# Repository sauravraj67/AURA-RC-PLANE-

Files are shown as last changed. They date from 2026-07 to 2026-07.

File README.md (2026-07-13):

# AURA-RC-PLANE-



I made a custom Tailless twin motor RC Plane with custom Flight Controller (based on STM32). The Flight Controller  will have a  IMU's and a barometer for precise data collection. The Plane design will include a tailless structure and the motions will be controlled by the flaps on the wings.

## Features
- Base on  STM32F401CBUx 
- Has dual IMU (MPU_6050)
- Has a Barometer (BMP280)
- Uses 2 Light-Weight Servoes
- Uses Custom flight-controller
- Tailless twin motor Design

### Schematic



###  PCB Design




### 3D Design


618795488-89bd397e-2dfa-4107-a2a6-26ff834b6018
618795522-03c98845-beb9-4136-b775-faca25e47061

## 📦 Bill of Materials

| Item | Quantity | Unit Price (USD) | Total Price (USD) | Source |
|---|:---:|---:|---:|---|
| PCB + PCBA | 1 | $154.46 | $140.56 | https://jlcpcb.com |
| PCB Shipping | 1 | $17.32 | $23.24 | https://jlcpcb.com |
| Brushless Motor | 2 | $15.20 | $30.40 | https://robu.in/product/r2207-2207-2450kv-ccw-fpv-brushless-motor/ |
| ESC | 2 | $8.91 | $17.82 | https://robocraze.com/products/simplifly-esc-30a-2s-6s-for-bldc-motors-with-d-shot-oneshot125 |
| Receiver / Transmitter | 1 | $62.00 | $62.00 |https://robocraze.com/products/fly-sky-fs-i6x-2-4ghz-6ch-afhds-2a-rc-transmitter-with-fs-ia10b-2-4ghz-10ch-receiver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 |
| 12V Battery | 1 | $5.78 | $5.78 | https://robocraze.com/products/11-1v-2200mah-li-ion-battery?_pos=18&_sid=25292ddd5&_ss=r |
| SG90 Servo | 2 | $0.96 | $1.92 | https://robocraze.com/products/sg90-micro-servo-motor?_pos=1&_sid=88e48e080&_ss=r |
| 3D Printed Plane | 1 | $0 | $0 | #Printing-legion |

## 💰 Cost Summary

| Category | Amount (USD) |
|---|---:|
| Total Component Cost | **$283.58** |

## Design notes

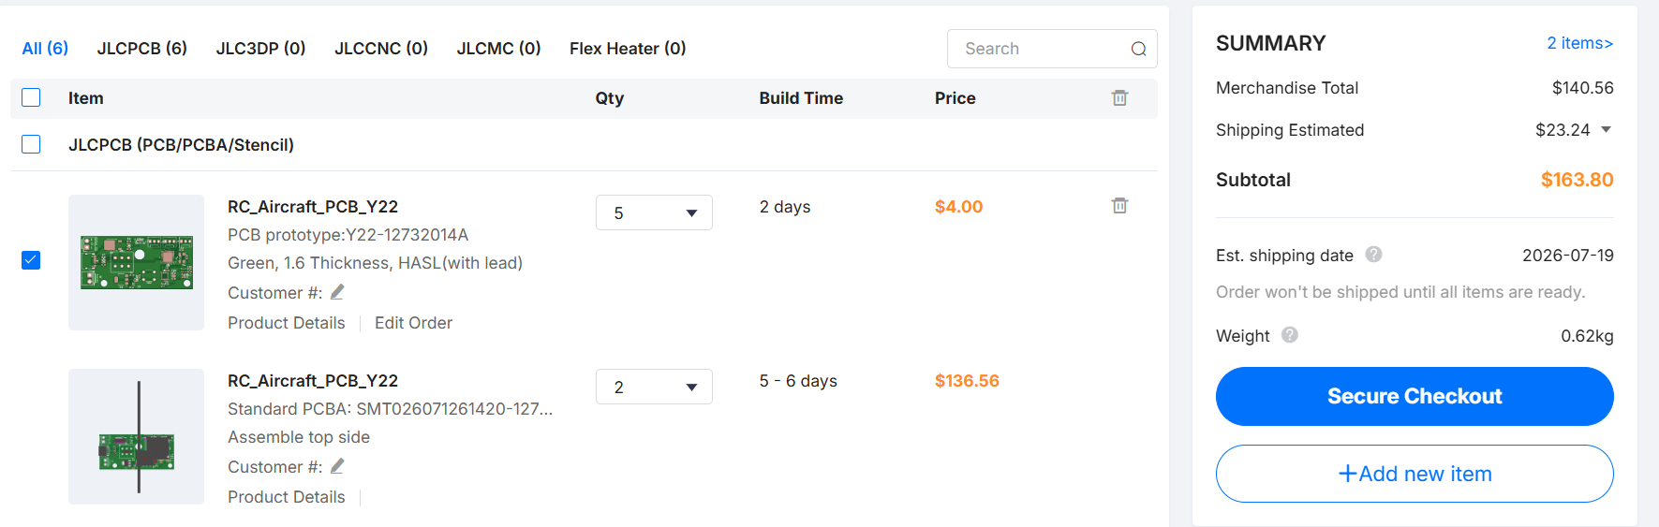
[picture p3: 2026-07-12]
Payment-ScreenShot/Screenshot 2026-07-13 011824.png

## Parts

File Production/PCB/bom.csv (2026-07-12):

Designator | Footprint | Quantity | Value | LCSC Part #
C1, C3, C7 | 0603 | 3 | 10 uf
C10, C9 | 0603 | 2 | 100nf
C11, C12 | 0603 | 2 | 12 pf
C13, C15, C16, C17 | 0603 | 4 | 100 pf
C2, C4, C5, C8 | 0603 | 4 | 0.1uf
C6 | 0603 | 1 | 2.2 uf
D1, D2 | 0201 | 2 | LED
J1 | USB_C_Receptacle_HRO_TYPE-C-31-M-12 | 1 | USB_C_Receptacle_USB2.0_16P
J2, J6 | JWT_A3963_1x02_P3.96mm_Vertical | 2 | Conn_01x02_Pin
J3, J4, J5 | FanPinHeader_1x03_P2.54mm_Vertical | 3 | Conn_01x03_Pin
J7 | PinHeader_1x04_P1.00mm_Vertical | 1 | Conn_01x04_Pin
R1, R2 | 0603 | 2 | 33 R
R3 | 0603 | 1 | 50 K
R4 | 0603 | 1 | 50K
R5, R6 | 0603 | 2 | 1k
R7 | 0603 | 1 | 1 K
SW1 | SW_PUSH_E-Switch_FS5700DP_DPDT | 1 | SW_DPDT_x2
SW2 | SW_PUSH_6mm | 1 | SW_Push
U1 | SOT-223-3_TabPin2 | 1 | AMS1117-3.3
U2 | TO-252-2 | 1 | L7805
U3 | InvenSense_QFN-24_4x4mm_P0.5mm | 1 | MPU-6050
U4 | Bosch_LGA-8_2x2.5mm_P0.65mm_ClockwisePinNumbering | 1 | BMP280
U5 | QFN-48-1EP_7x7mm_P0.5mm_EP5.6x5.6mm | 1 | STM32F401CBUx
Y1 | Crystal_SMD_0603-4Pin_6.0x3.5mm | 1 | Crystal_GND24_Small

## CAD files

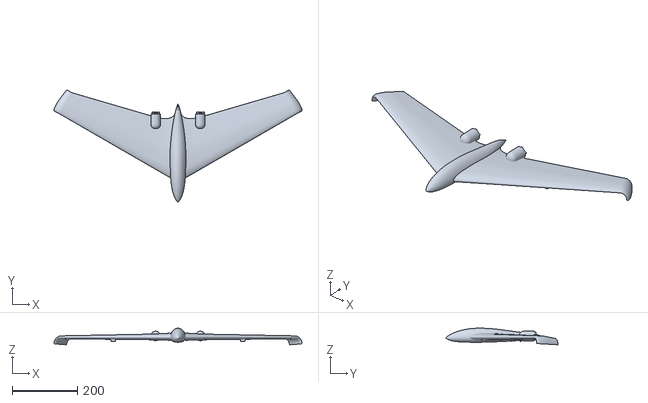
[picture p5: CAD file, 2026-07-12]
Production/CAD/AURA3D.stl
760.6 x 343.3 x 51.2

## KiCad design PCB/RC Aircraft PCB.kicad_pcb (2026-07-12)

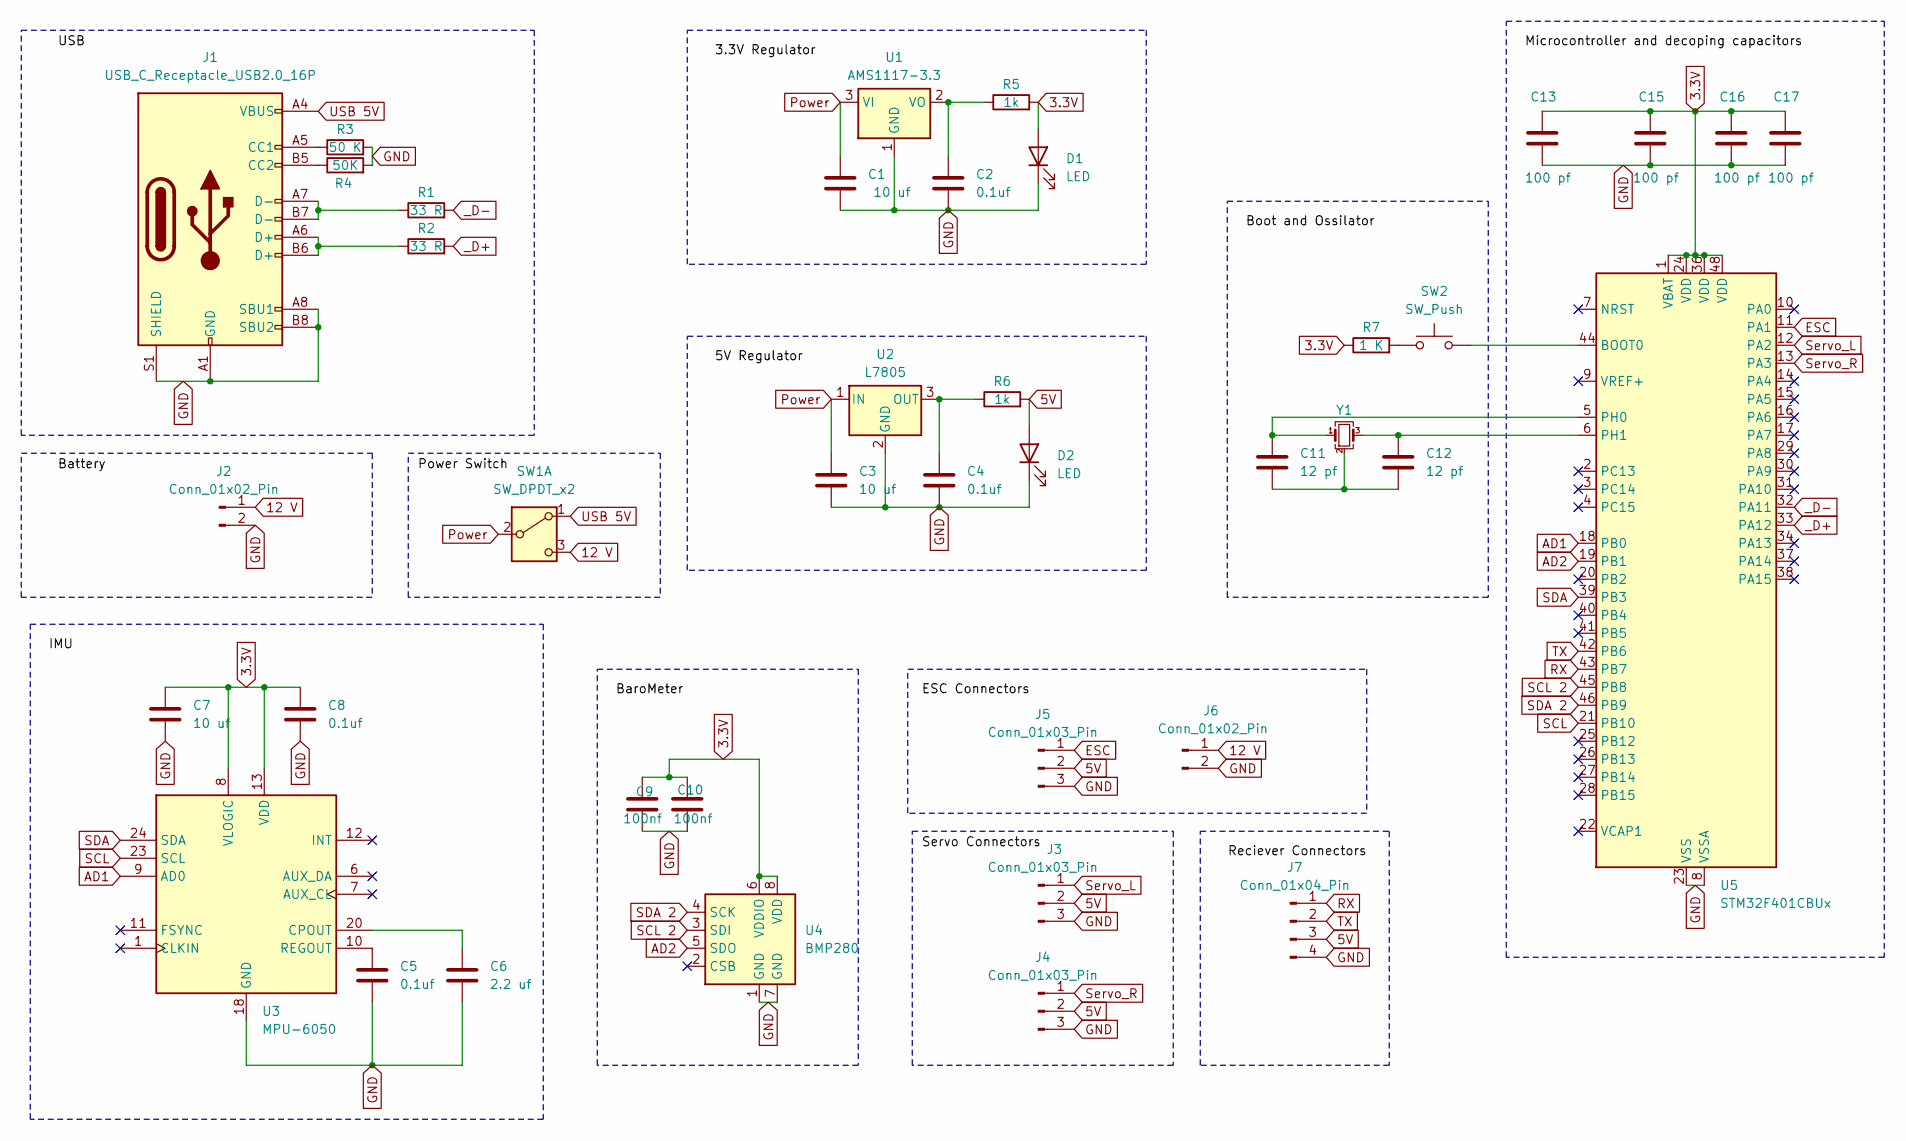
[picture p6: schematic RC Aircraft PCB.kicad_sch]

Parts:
C1, C3, C7: 10 uf; C_0603_1608Metric_Pad1.08x0.95mm_HandSolder
C2, C4, C5, C8: 0.1uf; C_0603_1608Metric_Pad1.08x0.95mm_HandSolder
C6: 2.2 uf; C_0603_1608Metric_Pad1.08x0.95mm_HandSolder
C9, C10: 100nf; C_0603_1608Metric_Pad1.08x0.95mm_HandSolder
C11, C12: 12 pf; C_0603_1608Metric_Pad1.08x0.95mm_HandSolder
C13, C15, C16, C17: 100 pf; C_0603_1608Metric_Pad1.08x0.95mm_HandSolder
D1, D2: LED; LED_0201_0603Metric
J1: USB_C_Receptacle_USB2.0_16P; USB_C_Receptacle_HRO_TYPE-C-31-M-12
J2, J6: Conn_01x02_Pin; JWT_A3963_1x02_P3.96mm_Vertical
J3, J4, J5: Conn_01x03_Pin; FanPinHeader_1x03_P2.54mm_Vertical
J7: Conn_01x04_Pin; PinHeader_1x04_P1.00mm_Vertical
R1, R2: 33 R; R_0603_1608Metric
R3: 50 K; R_0603_1608Metric
R4: 50K; R_0603_1608Metric
R5, R6: 1k; R_0603_1608Metric
R7: 1 K; R_0603_1608Metric
SW1: SW_DPDT_x2; SW_PUSH_E-Switch_FS5700DP_DPDT
SW2: SW_Push; SW_PUSH_6mm
U1: AMS1117-3.3; SOT-223-3_TabPin2
U2: L7805; TO-252-2
U3: MPU-6050; InvenSense_QFN-24_4x4mm_P0.5mm
U4: BMP280; Bosch_LGA-8_2x2.5mm_P0.65mm_ClockwisePinNumbering
U5: STM32F401CBUx; QFN-48-1EP_7x7mm_P0.5mm_EP5.6x5.6mm
Y1: Crystal_GND24_Small; Crystal_SMD_0603-4Pin_6.0x3.5mm

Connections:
3.3V: C7.1, C8.1, C9.1, C10.1, C13.1, C15.1, C16.1, C17.1, D1.2 (A), R5.2, R7.1, U3.8 (VLOGIC), U3.13 (VDD), U4.6 (VDDIO), U4.8 (VDD), U5.1 (VBAT), U5.24 (VDD), U5.36 (VDD), U5.48 (VDD)
5V: D2.2 (A), J3.2, J4.2, J5.2, J7.3, R6.2
12 V: J2.1, J6.1, SW1.3 (C)
AD1: U3.9 (AD0), U5.18 (PB0)
AD2: U4.5 (SDO), U5.19 (PB1)
ESC: J5.1, U5.11 (PA1)
GND: C1.2, C2.2, C3.2, C4.2, C5.2, C6.2, C7.2, C8.2, C9.2, C10.2, C13.2, C15.2, C16.2, C17.2, D1.1 (K), D2.1 (K), J1.A1 (GND), J1.A8 (SBU1), J1.A12 (GND), J1.B1 (GND), J1.B8 (SBU2), J1.B12 (GND), J1.S1 (SHIELD), J2.2, J3.3, J4.3, J5.3, J6.2, J7.4, R3.2, R4.2, U1.1 (GND), U2.2 (GND), U3.18 (GND), U4.1 (GND), U4.7 (GND), U5.8 (VSSA), U5.23 (VSS), U5.35 (VSS), U5.47 (VSS), U5.49 (VSS)
unnamed: C11.2, C12.2, Y1.2 (G), Y1.4 (G)
unnamed: J1.A5 (CC1), R3.1
unnamed: J1.B5 (CC2), R4.1
unnamed: J1.A6 (D+), J1.B6 (D+), R2.1
unnamed: J1.A7 (D-), J1.B7 (D-), R1.1
unnamed: R7.2, SW2.1
unnamed: C2.1, R5.1, U1.2 (VO)
unnamed: C4.1, R6.1, U2.3 (OUT)
unnamed: C6.1, U3.20 (CPOUT)
unnamed: C5.1, U3.10 (REGOUT)
unnamed: SW2.2, U5.44 (BOOT0)
unnamed: C11.1, U5.5 (PH0), Y1.1
unnamed: C12.1, U5.6 (PH1), Y1.3
Power: C1.1, C3.1, SW1.2 (B), U1.3 (VI), U2.1 (IN)
RX: J7.1, U5.43 (PB7)
SCL: U3.23 (SCL), U5.21 (PB10)
SCL 2: U4.3 (SDI), U5.45 (PB8)
SDA: U3.24 (SDA), U5.39 (PB3)
SDA 2: U4.4 (SCK), U5.46 (PB9)
Servo_L: J3.1, U5.12 (PA2)
Servo_R: J4.1, U5.13 (PA3)
TX: J7.2, U5.42 (PB6)
USB 5V: J1.A4 (VBUS), J1.A9 (VBUS), J1.B4 (VBUS), J1.B9 (VBUS), SW1.1 (A)
_D+: R2.2, U5.33 (PA12)
_D-: R1.2, U5.32 (PA11)

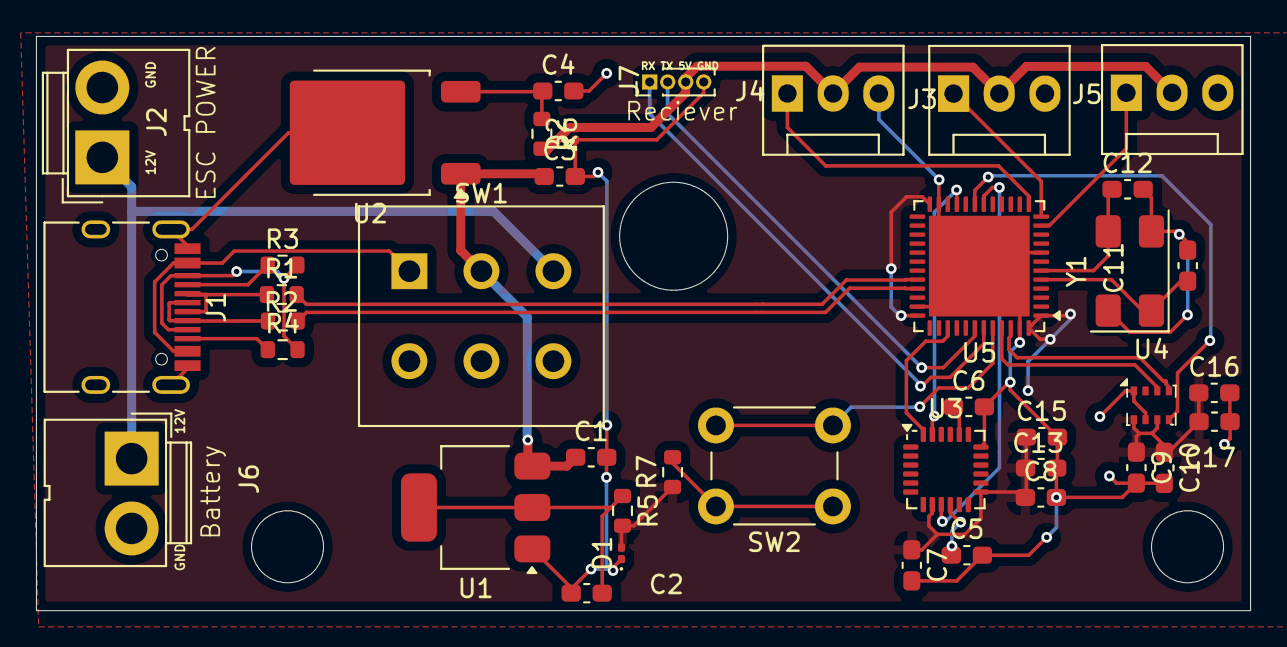
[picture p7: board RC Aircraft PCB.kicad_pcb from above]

Board: 2 copper layers, 67.4 x 31.9 mm, 40 parts (0 on the bottom side), 32 nets.

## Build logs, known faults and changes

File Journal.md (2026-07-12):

### So I am making an Custom RC Plane with custom Flight Controller

 ##  Schematics for Flight Controller
Hours - 6.1 hr

So I started with the schematics for my flight controller . I initially started with adding the USB-C ,12V battery connector and a 3 pin switch to switch between power from battery and USB-C as per the need them I made the circuit and added the labels then the STM32 and other sensores work on a constant 3.3V . So I added a 3.3V Voltage regulator (AMS1117-3.3) and made circuit for ir and added the required labels then the battery gives 12V but servos need 5V . So for that I added a 5V Voltage regulator (L7805) and made circuit for it and added the labels to them them as well after which  then I added the IMU (MPU5060) and barometer (BMP280) and made the required circuit for them and then I added the MCU (STM32F401CBUx) added the crystal oscillator circuit then I added the decoupling capacitors  added the boot button and attached all the labels from sensors , ESC ,Servos and USB to it as per it's pin outlet and this is the final look of the schematics  

## Making the PCB Layout 
hours :- 3.25 hr

So Now I started with the components placement . I First updated the PCB editor with all the components then I started arranging all the Component SET . I first made the USB-C circuit cluster arranged the required resistors around it then I started arranging the main chips in a very simple manner after that I started placing the Oscillator near to the MCU then I started arranging the IMU and barometer circuit . then I placed all the other components near to there connection and then I started forming a basic layout of the Board. IT is for a RC flight controller SO I would need to use a rectangular dimension instead of square for drones. then I placed the pins for batter ,servos and ESC made sure that they are near to there connection ,so that It is easy to rout . and after few alteration for ,I ended up with a final design. then I  added the boundary and added few holes on the PCB for connection ,Also I made sure that there is enough space for me to rout around the components. PCB (without rout)



## Routing the Fligh Controller 
hours :- 5.75 hr 

So I started with routing I initiated with the Data line connections , A connection hole was coming onto the path so for now I deleted it then I didn't specifically named the connection with _D+ and _D- without it kicad would do a differential pair , So I update the schematics then I made the differential pair for data lines. then I left the GND and 3.3V connections as I will use fil-zone on top layer for power and GND for bottom layer for stability. I used thicj traces for the 5V and 12V connections and I started making routs for the whole board one by one first I made the components circuit for sensors , routed the oscillator  to MCU then I started routing the 5v and 12v lines started routing the decoupling capacitors . I used vias where it was needed , made sure that the routs are clean and simple . I also had to made few changes on the PCB rout So that I can easily rout then I added 3.3V fillzone on top layer and GND fill zone to bottom layer and there were few miss connections , So I started solving them and then I used the Rules checker for any errors . I solved the major issues like  miss-Connections and rout near vias and holes  and left the basic the silkscreen ones. Then I added a text logo for the PCB and stared adding text for the naming the outpins and there connections . And this is the final looks of the Flight Controller PCB 

TOP Layer 



Bottom Layer 



3D View 



## Finalizing The Concept Design
hours :-  2.8 hr 

So Now I went and finalized the concept design . As I already Said before It will be a Tailless Twin motor RC Plane. So I kept that in mind and went and researched about that concept . After considering multiple design . I ended up liking one design then I selected a air-foil that would suit it and generated a reference design with TOP , FRONT and SIDE View of the plane with dimensions also with the Air-Foil. The Air-Foil I selected was MH-45 reflex . It is a 9.85%-thick reflex airfoil designed by Martin Hepperle specifically for flying wings and tailless model aircraft. So I added it as per my Design requirements. The Body Base is heavily inspired by
* Blended Wing-Body
* Sweepback Stability
* Integrated Twin Nacelles
And this is the final look of it



## Alligning the reference /Made the Fulelage 
hours :-  6.7 hr 

I loaded up the Fusion with the reference image then I Started aligning the reference to the exact size i wanted and then moved it to axis origin .I did it for all the 3 reference with as much precision as possible and this is how the 3D reference Canvas Lossets/6c143896-3292-4962-8e3e-9c78ffbe8cfb" />

. Then I made the side view Sketch of the main body


then I made the top view of the body


there were few sketch allignment issue so I solved them 


then after that I added offset plane for Rails . I  keeping in mind about the top/bottom sketch and the side sketches . In total I had to add about 19 of these offset planes and this is the look it looks


then for every offset plane I had to make rail . For that I needed to project Intersect all the for guildlines then use Spline to make that rails . this is how the first rail looked liked

and this was the end look after  I did it for all of the rails 


. It took me some times to reach here then I went to make the 3D model of the body using LOFT Feature but errors started showing up

I Tried to fix the errors but nothing much happened So I took a decision to rebuild it again because there wasn't any outcome I am goint to receive out of this . So Again I made the skectches of top and Side view





then again I went to make the model and waala this time things worked perfectly



Final Fuselage look 



## Made the Wings 
hours :-  3.4 hr 

So I made the airfoil first


then I aligned it to the fuselage

fter that I made the guild sketch's of the wing
hen I made the 3D model of the wing

then I extruded it and repeated the same for the other Side and this is how it looks 




then I added stabalizers to the end of the wings and this is the final look 



then I made cuts for mobility and component fixing 




## Finilized the CAD
hours :-  4.2 hr 

First I made the Surface to which I will attach the motors

then I added the rest of the eternal components like the Flight controller , Battery ,Receiver and ESC





that I added the servos to there respective position

Then I made respective cut's and fix for the servoes and the Brushless motors using sketch and offset plane tools 








So this is the final polished LOOK



## Made the firmware
hours :-  3.2  hr 

So I made a main firmware that Supercharges the Brain and then Wakes up the sensors and takes reading from them with calibration. the 200 Hz Flight Loop Reading and Fuse the data from the sensors from (IMU's and Barometer ) . Calculates acceleration ,gravity Wing speed . Then Use PID Stabilization . then reads the reading from the receiver and Controllers the Servos and ESC's accordingly as per the Input.



AND WITH THAT THE PROJECT COMES TO AN END !!!

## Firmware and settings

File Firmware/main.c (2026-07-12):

/*
 * ============================================================================
 * CUSTOM TAILLESS TWIN-MOTOR FLIGHT CONTROLLER FIRMWARE
 * Target MCU: STM32F401CBUx
 * ============================================================================
 */

#include "main.h"
#include <math.h>

// --- DEFINITIONS & CONSTANTS ---
#define MPU6050_ADDR    (0x68 << 1)
#define BMP280_ADDR     (0x76 << 1)
#define SBUS_FRAME_SIZE 25

// --- PERIPHERAL HANDLES ---
I2C_HandleTypeDef hi2c1;   // IMU 1 (MPU6050) via PB6/PB7
I2C_HandleTypeDef hi2c2;   // Barometer (BMP280) via PB10/PB3
TIM_HandleTypeDef htim1;   // ESCs (PA8, PA9)
TIM_HandleTypeDef htim2;   // Servos (PA0, PA1)
UART_HandleTypeDef huart1; // SBUS Receiver Input (PA10)

// --- FLIGHT CONTROL VARIABLES ---
float roll_input = 0.0f, pitch_input = 0.0f, throttle_input = 1000.0f;
float current_roll = 0.0f, current_pitch = 0.0f;
float gyro_bias_x = 0.0f, gyro_bias_y = 0.0f;

// PID Tuning Constants (Adjust these during test flights)
float Kp_roll = 1.2f,  Ki_roll = 0.05f,  Kd_roll = 0.1f;
float Kp_pitch = 1.5f, Ki_pitch = 0.05f, Kd_pitch = 0.1f;

// PID Memory Registers
float error_roll, integral_roll, derivative_roll, last_error_roll, out_roll;
float error_pitch, integral_pitch, derivative_pitch, last_error_pitch, out_pitch;

// SBUS Protocol Variables
uint8_t sbus_buffer[SBUS_FRAME_SIZE];
uint16_t sbus_channels[4];
uint8_t sbus_index = 0;
uint8_t is_armed = 0;
uint8_t rx_byte;

// Barometer Calibration Factors
uint16_t dig_T1; int16_t dig_T2, dig_T3; uint16_t dig_P1;
int16_t dig_P2, dig_P3, dig_P4, dig_P5, dig_P6, dig_P7, dig_P8, dig_P9;

// --- FUNCTION PROTOTYPES ---
void SystemClock_Config(void);
static void MX_GPIO_Init(void);
static void MX_I2C1_Init(void);
static void MX_I2C2_Init(void);
static void MX_TIM1_Init(void);
static void MX_TIM2_Init(void);
static void MX_USART1_UART_Init(void);

void IMU_Calibrate(void);
void IMU_Read(float *r, float *p);
void BMP280_Init(void);
float BMP280_GetAltitude(void);
void Mix_Elevons(float throttle, float roll, float pitch);

// --- MAIN PROGRAM EXECUTION ---
int main(void) {
    // Reset of all peripherals, Initializes the Flash interface and the Systick.
    HAL_Init();

    // Configure the system clock to 84 MHz using the 25MHz external crystal
    SystemClock_Config();

    // Initialize all configured peripherals
    MX_GPIO_Init();
    MX_I2C1_Init();
    MX_I2C2_Init();
    MX_TIM1_Init();
    MX_TIM2_Init();
    MX_USART1_UART_Init();

    // Device Sensors Boot & Calibration Sequence
    BMP280_Init();
    IMU_Calibrate();
    
    // Start Non-blocking UART Reception for RC Signal
    HAL_UART_Receive_IT(&huart1, &rx_byte, 1);

    // Start PWM Hardware Timers
    HAL_TIM_PWM_Start(&htim1, TIM_CHANNEL_1); // Left ESC
    HAL_TIM_PWM_Start(&htim1, TIM_CHANNEL_2); // Right ESC
    HAL_TIM_PWM_Start(&htim2, TIM_CHANNEL_1); // Left Servo
    HAL_TIM_PWM_Start(&htim2, TIM_CHANNEL_2); // Right Servo

    uint32_t loop_timer = HAL_GetTick();

    while (1) {
        // Main Flight Controller Loop (Executes strictly at 200Hz -> every 5ms)
        if ((HAL_GetTick() - loop_timer) >= 5) {
            loop_timer = HAL_GetTick();

            // 1. Refresh Flight Performance Matrix Data
            IMU_Read(&current_roll, &current_pitch);
            float current_altitude = BMP280_GetAltitude();

            // 2. Structural Safety Timeout Arm Interlock
            if (!is_armed) {
                __HAL_TIM_SET_COMPARE(&htim1, TIM_CHANNEL_1, 1000); // Force Motors Off
                __HAL_TIM_SET_COMPARE(&htim1, TIM_CHANNEL_2, 1000);
                continue; // Skip PID execution if safety switch is down
            }

            // 3. Roll Axis PID Controller
            error_roll = roll_input - current_roll;
            integral_roll += error_roll * 0.005f;
            derivative_roll = (error_roll - last_error_roll) / 0.005f;
            out_roll = (Kp_roll * error_roll) + (Ki_roll * integral_roll) + (Kd_roll * derivative_roll);
            last_error_roll = error_roll;

            // 4. Pitch Axis PID Controller
            error_pitch = pitch_input - current_pitch;
            integral_pitch += error_pitch * 0.005f;
            derivative_pitch = (error_pitch - last_error_pitch) / 0.005f;
            out_pitch = (Kp_pitch * error_pitch) + (Ki_pitch * integral_pitch) + (Kd_pitch * derivative_pitch);
            last_error_pitch = error_pitch;

            // 5. Send Mixed Commands to Control Surfaces and Power Units
            Mix_Elevons(throttle_input, out_roll, out_pitch);
        }
    }
}

// --- MIXING & CONTROL SURFACE LOGIC ---
void Mix_Elevons(float throttle, float roll, float pitch) {
    // Elevon Aerodynamic Mixer Logic for Tailless Aircraft
    float s_left  = 1500 + pitch + roll;
    float s_right = 1500 - pitch + roll;

    // Hard Clip Servo Output Constraints (1000us to 2000us)
    s_left  = (s_left > 2000) ? 2000 : ((s_left < 1000) ? 1000 : s_left);
    s_right = (s_right > 2000) ? 2000 : ((s_right < 1000) ? 1000 : s_right);

    __HAL_TIM_SET_COMPARE(&htim2, TIM_CHANNEL_1, (uint32_t)s_left);
    __HAL_TIM_SET_COMPARE(&htim2, TIM_CHANNEL_2, (uint32_t)s_right);

    // Twin Engine Differential Thrust Mixing to assist Yaw Control
    float esc_l = throttle + (roll * 0.15f);
    float esc_r = throttle - (roll * 0.15f);

    // Protect against motor overflow parameters
    esc_l = (esc_l > 2000) ? 2000 : ((esc_l < 1000) ? 1000 : esc_l);
    esc_r = (esc_r > 2000) ? 2000 : ((esc_r < 1000) ? 1000 : esc_r);

    __HAL_TIM_SET_COMPARE(&htim1, TIM_CHANNEL_1, (uint32_t)esc_l);
    __HAL_TIM_SET_COMPARE(&htim1, TIM_CHANNEL_2, (uint32_t)esc_r);
}

// --- IMU TRANSLATION & CALIBRATION DRIVERS ---
void IMU_Calibrate(void) {
    uint8_t data[6];
    int32_t gx = 0, gy = 0;
    
    // Hold completely level and stable during initialization
    for (int i = 0; i < 400; i++) {
        HAL_I2C_Mem_Read(&hi2c1, MPU6050_ADDR, 0x43, I2C_MEMADD_SIZE_8BIT, data, 6, 10);
        gx += (int16_t)((data[0] << 8) | data[1]);
        gy += (int16_t)((data[2] << 8) | data[3]);
        HAL_Delay(2);
    }
    gyro_bias_x = (float)gx / 400.0f / 65.5f;
    gyro_bias_y = (float)gy / 400.0f / 65.5f;
}

void IMU_Read(float *r, float *p) {
    uint8_t data[6];
    HAL_I2C_Mem_Read(&hi2c1, MPU6050_ADDR, 0x3B, I2C_MEMADD_SIZE_8BIT, data, 6, 10);
    int16_t ax = (data[0] << 8) | data[1];
    int16_t ay = (data[2] << 8) | data[3];
    int16_t az = (data[4] << 8) | data[5];

    // Compute Pitch/Roll orientation vectors from Accelerometer forces
    float acc_roll  = atan2f((float)ay, (float)az) * 57.2957f;
    float acc_pitch = atan2f(-(float)ax, sqrtf((float)ay*(float)ay + (float)az*(float)az)) * 57.2957f;

    // Complimentary Noise Filtering step
    *r = 0.98f * (*r) + 0.02f * acc_roll;
    *p = 0.98f * (*p) + 0.02f * acc_pitch;
}

// --- BAROMETER SENSOR INTERFACE ---
void BMP280_Init(void) {
    uint8_t calib[24], config[2] = {0xF4, 0x57};
    HAL_I2C_Mem_Read(&hi2c2, BMP280_ADDR, 0x88, I2C_MEMADD_SIZE_8BIT, calib, 24, 100);
    
    dig_T1 = (calib[1] << 8) | calib[0]; dig_T2 = (calib[3] << 8) | calib[2];
    dig_P1 = (calib[7] << 8) | calib[6]; dig_P2 = (calib[9] << 8) | calib[8];
    
    HAL_I2C_Master_Transmit(&hi2c2, BMP280_ADDR, config, 2, 100);
}

float BMP280_GetAltitude(void) {
    uint8_t data[6];
    HAL_I2C_Mem_Read(&hi2c2, BMP280_ADDR, 0xF7, I2C_MEMADD_SIZE_8BIT, data, 3, 100);
    int32_t adc_P = (data[0] << 12) | (data[1] << 4) | (data[2] >> 4);
    
    // Returns estimated altitude value in relative meters
    return 44330.0f * (1.0f - powf(((float)adc_P / 256.0f) / 101325.0f, 0.1903f));
}

// --- INTERRUPT BASED SBUS DATA RECEIVER ---
void HAL_UART_RxCpltCallback(UART_HandleTypeDef *huart) {
    if (huart->Instance == USART1) {
        uint8_t byte = rx_byte;
        
        if (sbus_index == 0 && byte != 0x0F) return; // Verify frame start bit
        
        sbus_buffer[sbus_index++] = byte;
        
        if (sbus_index == SBUS_FRAME_SIZE) {
            sbus_index = 0;
            if (sbus_buffer[24] == 0x00) { // Verify validity of end bit sequence
                sbus_channels[0] = ((sbus_buffer[1] | sbus_buffer[2] << 8) & 0x07FF);
                sbus_channels[1] = ((sbus_buffer[2] >> 3 | sbus_buffer[3] << 5) & 0x07FF);
                sbus_channels[2] = ((sbus_buffer[3] >> 6 | sbus_buffer[4] << 2) & 0x07FF);
                
                // Normalization mapping into standard PWM scale inputs
                roll_input     = (1000 + ((sbus_channels[0] - 172) * 1000 / 1639)) - 1500;
                pitch_input    = (1000 + ((sbus_channels[1] - 172) * 1000 / 1639)) - 1500;
                throttle_input = 1000 + ((sbus_channels[2] - 172) * 1000 / 1639);
                
                // Read specific bit flags to check the configuration state of safety switch
                is_armed = (sbus_buffer[23] & 0x01); 
            }
        }
        HAL_UART_Receive_IT(&huart1, &rx_byte, 1); // Re-arm the interrupt listener
    }
}

// --- HARDWARE SYSTEM CLOCK CONFIGURATION (84 MHz via HSE) ---
void SystemClock_Config(void) {
    RCC_OscInitTypeDef RCC_OscInitStruct = {0};
    RCC_ClkInitTypeDef RCC_ClkInitStruct = {0};

    __HAL_RCC_PWR_CLK_ENABLE();
    __HAL_PWR_VOLTAGESCALING_CONFIG(PWR_REGULATOR_VOLTAGE_SCALE_2);

    RCC_OscInitStruct.OscillatorType = RCC_OSCILLATORTYPE_HSE;
    RCC_OscInitStruct.HSEState = RCC_HSE_ON;
    RCC_OscInitStruct.PLL.PLLState = RCC_PLL_ON;
    RCC_OscInitStruct.PLL.PLLSource = RCC_PLLSOURCE_HSE;
    RCC_OscInitStruct.PLL.PLLM = 25;
    RCC_OscInitStruct.PLL.PLLN = 336;
    RCC_OscInitStruct.PLL.PLLP = RCC_PLLP_DIV4;
    RCC_OscInitStruct.PLL.PLLQ = 7;
    HAL_RCC_OscConfig(&RCC_OscInitStruct);

    RCC_ClkInitStruct.ClockType = RCC_CLOCKTYPE_HCLK|RCC_CLOCKTYPE_SYSCLK|RCC_CLOCKTYPE_PCLK1|RCC_CLOCKTYPE_PCLK2;
    RCC_ClkInitStruct.SYSCLKSource = RCC_SYSCLKSOURCE_PLLCLK;
    RCC_ClkInitStruct.AHBCLKDivider = RCC_SYSCLK_DIV1;
    RCC_ClkInitStruct.APB1CLKDivider = RCC_DIV2;
    RCC_ClkInitStruct.APB2CLKDivider = RCC_DIV1;
    HAL_RCC_ClockConfig(&RCC_ClkInitStruct, FLASH_LATENCY_2);
}

// --- BASIC PERIPHERAL LOW LEVEL INITIALIZERS ---
static void MX_I2C1_Init(void) {
    hi2c1.Instance = I2C1;
    hi2c1.Init.ClockSpeed = 100000;
    hi2c1.Init.DutyCycle = I2C_DUTYCYCLE_2;
    hi2c1.Init.OwnAddress1 = 0;
    hi2c1.Init.AddressingMode = I2C_ADDRESSINGMODE_7BIT;
    HAL_I2C_Init(&hi2c1);
}

static void MX_I2C2_Init(void) {
    hi2c2.Instance = I2C2;
    hi2c2.Init.ClockSpeed = 100000;
    hi2c2.Init.DutyCycle = I2C_DUTYCYCLE_2;
    HAL_I2C_Init(&hi2c2);
}

static void MX_TIM1_Init(void) {
    TIM_OC_InitTypeDef sConfigOC = {0};
    htim1.Instance = TIM1;
    htim1.Init.Prescaler = 84-1; // Clock tick resolution becomes 1 microsecond
    htim1.Init.Period = 20000-1; // 20ms Frame period -> 50Hz PWM Output frequency
    HAL_TIM_PWM_Init(&htim1);
    sConfigOC.OCMode = TIM_OCMODE_PWM1;
    sConfigOC.Pulse = 1000; // Initialize at safe idle pulse threshold
    HAL_TIM_PWM_ConfigChannel(&htim1, &sConfigOC, TIM_CHANNEL_1);
    HAL_TIM_PWM_ConfigChannel(&htim1, &sConfigOC, TIM_CHANNEL_2);
}

static void MX_TIM2_Init(void) {
    TIM_OC_InitTypeDef sConfigOC = {0};
    htim2.Instance = TIM2;
    htim2.Init.Prescaler = 84-1;
    htim2.Init.Period = 20000-1;
    HAL_TIM_PWM_Init(&htim2);
    sConfigOC.OCMode = TIM_OCMODE_PWM1;
    sConfigOC.Pulse = 1500; // Stabilize servos at exact midpoint baseline
    HAL_TIM_PWM_ConfigChannel(&htim2, &sConfigOC, TIM_CHANNEL_1);
    HAL_TIM_PWM_ConfigChannel(&htim2, &sConfigOC, TIM_CHANNEL_2);
}

static void MX_USART1_UART_Init(void) {
    huart1.Instance = USART1;
    huart1.Init.BaudRate = 100000; // Exact structural transmission frequency of SBUS
    huart1.Init.WordLength = UART_WORDLENGTH_9B;
    huart1.Init.StopBits = UART_STOPBITS_2;
    huart1.Init.Parity = UART_PARITY_EVEN;
    huart1.Init.Mode = UART_MODE_TX_RX;
    HAL_UART_Init(&huart1);
}

static void MX_GPIO_Init(void) {
    __HAL_RCC_GPIOH_CLK_ENABLE();
    __HAL_RCC_GPIOA_CLK_ENABLE();
    __HAL_RCC_GPIOB_CLK_ENABLE();
}
